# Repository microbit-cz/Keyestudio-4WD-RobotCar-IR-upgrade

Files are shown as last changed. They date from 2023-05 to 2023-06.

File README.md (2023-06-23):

[IR_MD]: /assets/languages/master/ir_setup.md
[models_MD]: /assets/languages/master/models_download.md
[crimping_MD]: /assets/languages/master/crimping_cables.md
[nuts_MD]: /assets/languages/master/nut_insertion.md
[charge_MD]: /assets/languages/master/charging_setup.md
[czechLanguage_MD]: /assets/languages/czech/README.cs.md
[englishLanguage_MD]: /README.md
[productFoto]: /assets/img/welcome.jpg

# Wall Detection and Integrated Charging addition for KS4031 Keyestudio 4WD Mecanum Robot Car

<kbd>[Czech][czechLanguage_MD]</kbd> <kbd>[English][englishLanguage_MD]</kbd>

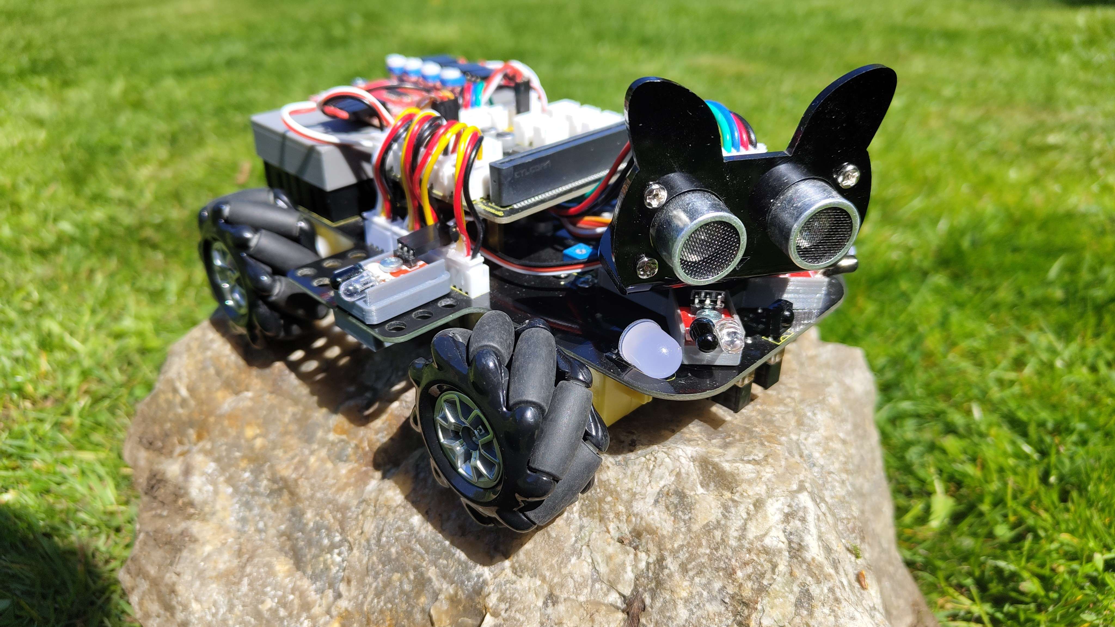
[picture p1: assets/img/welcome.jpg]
Welcome!


The **[wall detection][IR_MD]** feature uses sensors to detect the presence of obstacles in 180° radius such as walls and other objects in the car's path, allowing the car to automatically stop or change its direction to avoid collisions. This feature can be particularly useful in situations where the car is operating in a confined space or navigating through a complex environment such as Maze.

The **[integrated charging][charge_MD]** through USB-C can save time and improve convenience by allowing users to quickly and easily recharge the car without the need for additional equipment or cables.

## Documentation

- **[Download Models][models_MD]**
- [How to set-up wall detection][IR_MD]
- [How to set-up integrated charging][charge_MD]
- [Nut insertion][nuts_MD]
- [Cable crimping][crimping_MD]

---

## Functionality test

```js
pins.setPull(DigitalPin.P0, PinPullMode.PullNone);
pins.setPull(DigitalPin.P7, PinPullMode.PullNone);
pins.setPull(DigitalPin.P12, PinPullMode.PullNone);
pins.setPull(DigitalPin.P13, PinPullMode.PullNone);

while (true) {
  let front_P = pins.digitalReadPin(DigitalPin.P12);
  let front_L = pins.digitalReadPin(DigitalPin.P7);
  let left = pins.digitalReadPin(DigitalPin.P0);
  let right = pins.digitalReadPin(DigitalPin.P13);

  console.log("front_P: " + front_P);
  console.log("front_L: " + front_L);
  console.log("left: " + left);
  console.log("right: " + right);
  pause(100);
}
```

The given code snippet assigns the digital readings from the IR sensors to respective variables: front_P, front_L, left, and right. The console.log statements display the values of each sensor to the Console.

---

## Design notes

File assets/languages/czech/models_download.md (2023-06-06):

# Modely ke stažení

Zde jsou odkazy ke stažení modelů ve dvou různých formátech.

---

## Přidání IR senzoru

| Model | .SLDPRT | .STL | reference photo |
| --- | --- | --- | --- |
| **Balíček**  | [Stáhnout](/assets/models/IR_bundle_SLDPRT.zip) | [Stáhnout](/assets/models/stl/IR_bundle_STL.zip) | --------------------------- |
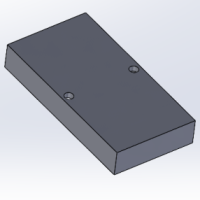
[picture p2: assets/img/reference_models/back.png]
back lid
| Zadní Víko | [Stáhnout](/assets/models/back.SLDPRT) | [Stáhnout](/assets/models/stl/back.STL) |  |
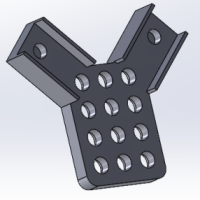
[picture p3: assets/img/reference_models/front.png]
front piece
| Přední díl  | [Stáhnout](/assets/models/front.SLDPRT) | [Stáhnout](/assets/models/stl/front.STL) |  |
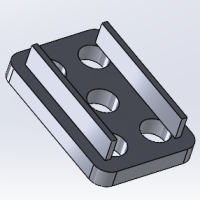
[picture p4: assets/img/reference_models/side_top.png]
side top piece
| Boční vrchní | [Stáhnout](/assets/models/side_top.SLDPRT) | [Stáhnout](/assets/models/stl/side_top.STL) |  |
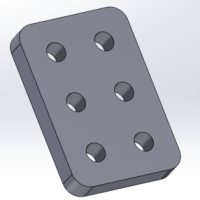
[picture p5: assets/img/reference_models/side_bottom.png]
side bottom piece
| Boční Spodní | [Stáhnout](/assets/models/side_bottom.SLDPRT) | [Stáhnout](/assets/models/stl/side_bottom.STL) |  |

## Integrované nabíjení

| Model | .SLDPRT | .STL | reference photo |
| --- | --- | --- | --- |
| **Balíček**  | [Stáhnout](/assets/models/Charger_bundle_SLDPRT.zip) | [Stáhnout](/assets/models/stl/Charger_bundle_STL.zip) | --------------------------- |
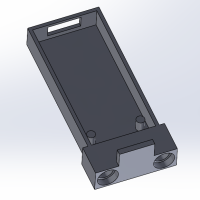
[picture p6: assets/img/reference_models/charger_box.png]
Box nabíječe
| Charger Box | [Stáhnout](/assets/models/charger_box.SLDPRT) | [Stáhnout](/assets/models/stl/charger_box.STL) |  |
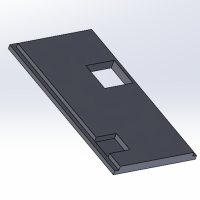
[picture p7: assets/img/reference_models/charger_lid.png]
Charger Lid
| Víko nabíječe | [Stáhnout](/assets/models/charger_lid.SLDPRT) | [Stáhnout](/assets/models/stl/charger_lid.STL) |  |

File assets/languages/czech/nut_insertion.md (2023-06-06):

# Jak vložit zasouvací matici

## Krok 1:

Ujistěte se, že je 3D vytištěný díl čistý a bez jakýchkoli nečistot nebo hrubých hran. V případě potřeby použijte smirkový papír k vyhlazení případných nerovností.

## Krok 2: Příprava zasouvací matice

Pomocí kleští přidržte matici na místě a vložte šroub do otvoru se závitem, abyste se ujistili, že jsou závity čisté a vyrovnané.

## Krok 3: Nasaďte zasouvací matici

Opatrně nasaďte nasazovací matici (závitem dolů) na otvor 3D tištěného dílu. Přidržte matici na místě pomocí kleští a ujistěte se, že je v otvoru vyrovnaná a vycentrovaná.

## Krok 4: Pájecí pistolí zahřejte matici 

S nasazenou maticí se dotkněte hrotem pájecí pistole matice. Na několik sekund přiložte teplo, dokud se matice nezačne tavit do 3D tištěného dílu, a ujistěte se, že na horní straně zůstává ~1 mm.

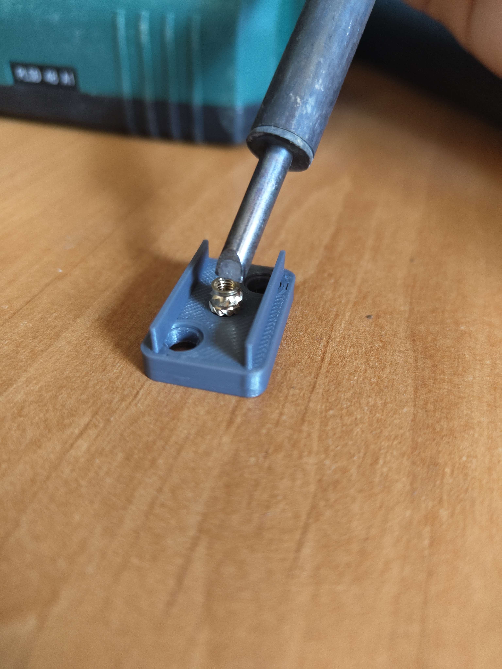
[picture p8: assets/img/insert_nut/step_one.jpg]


## Krok 5: Nechte vychladnout

Jakmile se matice roztaví v 3D tištěném dílu, vyjměte pájecí pistoli a nechte díl vychladnout. To by mělo trvat jen několik sekund.

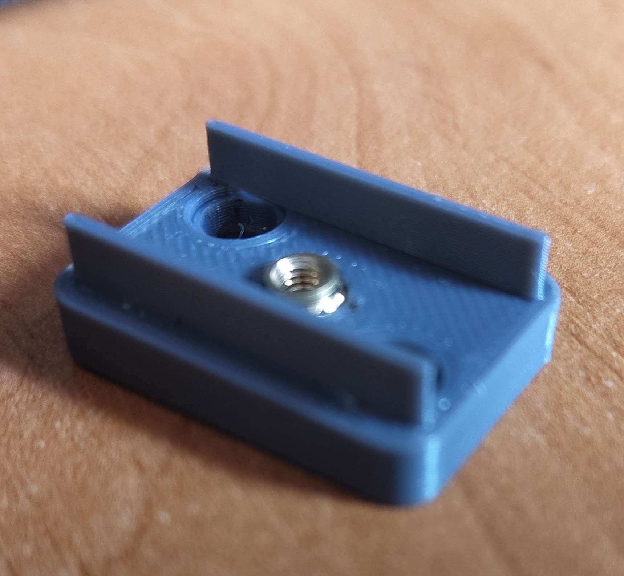
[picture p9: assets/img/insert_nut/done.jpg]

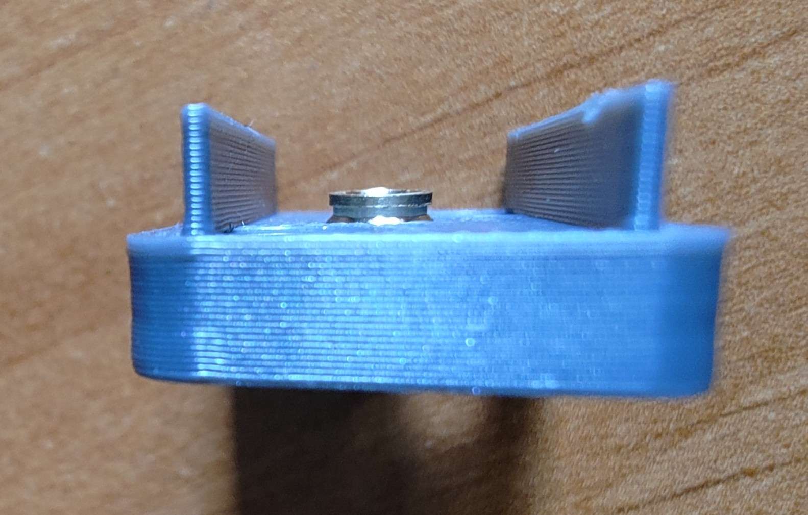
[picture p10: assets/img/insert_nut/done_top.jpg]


---

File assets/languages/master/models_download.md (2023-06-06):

# Model Downloads

Here are the downloadable links for the models in two different formats.

---

## IR sensor addition

| Model | .SLDPRT | .STL | reference photo |
| --- | --- | --- | --- |
| **BUNDLE**  | [Download](/assets/models/IR_bundle_SLDPRT.zip) | [Download](/assets/models/stl/IR_bundle_STL.zip) | --------------------------- |
| Back Lid | [Download](/assets/models/back.SLDPRT) | [Download](/assets/models/stl/back.STL) | back lid |
| Front Part  | [Download](/assets/models/front.SLDPRT) | [Download](/assets/models/stl/front.STL) | front piece |
| Side Top | [Download](/assets/models/side_top.SLDPRT) | [Download](/assets/models/stl/side_top.STL) | side top piece |
| Side Bottom | [Download](/assets/models/side_bottom.SLDPRT) | [Download](/assets/models/stl/side_bottom.STL) | side bottom piece |

## Integrated charging addition

| Model | .SLDPRT | .STL | reference photo |
| --- | --- | --- | --- |
| **BUNDLE**  | [Download](/assets/models/Charger_bundle_SLDPRT.zip) | [Download](/assets/models/stl/Charger_bundle_STL.zip) | --------------------------- |
| Charger Box | [Download](/assets/models/charger_box.SLDPRT) | [Download](/assets/models/stl/charger_box.STL) | Charger Box |
| Charger Lid | [Download](/assets/models/charger_lid.SLDPRT) | [Download](/assets/models/stl/charger_lid.STL) | Charger Lid |

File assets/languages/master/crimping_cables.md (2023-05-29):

# How to Crimp Dupont Cables

Materials you will need:

- Dupont connector pins
- Dupont connector housing
- Crimping tool
- Wire cutter (knife or pliers)
- Stranded wire

## Step 1: Cut the wire to the desired length

Using the wire cutter, cut the stranded wire to the desired length. Make sure to leave a little extra length for crimping.

## Step 2: Insert the wire into the connector pin

Insert the stripped end of the wire into the connector pin. Make sure the wire goes all the way into the pin and that the strands are lined up evenly with the end of the pin.

## Step 3: Crimp the connector pin

Using the crimping tool, crimp the pin onto the wire. Be sure to position the crimping tool so that it is centered on the pin and that the jaws of the tool are fully engaged before squeezing.

## Step 4: Insert the pin into the connector housing

Insert the pin into the appropriate slot in the connector housing. Make sure the pin clicks into place and that the wire is held firmly in the housing.

## Step 5: Repeat for other wires

Repeat steps 2-4 for each wire that needs to be crimped onto a connector pin.

## Step 6: Connect the connectors

Once all the wires are crimped and inserted into the connector housing, you can connect the connectors to each other. Be sure to match the pins and sockets properly so that they click into place and the connection is secure.

---

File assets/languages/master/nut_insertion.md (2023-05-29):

# How to insert a Insertion Nut

## Step 1:

Make sure the 3D printed part is clean and free of any debris or rough edges. If necessary, use sandpaper to smooth out any rough spots.

## Step 2: Prepare the insertion nut

Using pliers, hold the nut in place and insert a screw into the threaded hole to make sure the threads are clean and aligned.

## Step 3: Insert the insertion nut

Carefully place the insertion nut (thread down) on the hole of the 3D printed part. Hold the nut in place with pliers, ensuring that it is level and centered in the hole.

## Step 4: Apply heat with the soldering gun

With the insertion nut held in place, touch the tip of the soldering gun to the nut. Apply heat for a few seconds, until the nut begins to melt into the 3D printed part, make sure you leave ~1mm on the top.

Reference Photo

## Step 5: Allow to cool

Once the nut has melted into the 3D printed part, remove the soldering gun and allow the part to cool. This should only take a few seconds.

Reference Photo
Reference Photo

---

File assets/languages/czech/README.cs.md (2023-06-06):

[IR_MD]: /assets/languages/czech/ir_setup.md
[models_MD]: /assets/languages/czech/models_download.md
[crimping_MD]: /assets/languages/czech/crimping_cables.md
[nuts_MD]: /assets/languages/czech/nut_insertion.md
[charge_MD]: /assets/languages/czech/charging_setup.md
[czechLanguage_MD]: README.cs.md
[englishLanguage_MD]: /README.md
[productFoto]: /assets/img/welcome.jpg

# Detekce na zdi a integrované nabíjení pro robotické auto KS4031 Keyestudio 4WD Mecanum

<kbd>[Czech][czechLanguage_MD]</kbd> <kbd>[English][englishLanguage_MD]</kbd>

Welcome!

Funkce **[detekce stěn][IR_MD]** využívá senzory k detekci přítomnosti překážek v okruhu 180°, jako jsou stěny a další objekty v dráze vozu, a umožňuje vozu automaticky zastavit nebo změnit směr jízdy, aby se vyhnul kolizi. Tato funkce může být užitečná zejména v situacích, kdy se vůz pohybuje v omezeném prostoru nebo projíždí složitým prostředím, jako je například Bludiště.

**[Integrované nabíjení][charge_MD]** přes USB-C může ušetřit čas a zvýšit pohodlí, protože umožňuje uživatelům rychle a snadno dobíjet auto bez potřeby dalšího vybavení nebo kabelů.

## Dokumentace

- **[Modely ke stažení][models_MD]**
- [Jak nastavit detekci stěn][IR_MD]
- [Jak nastavit integrované nabíjení][charge_MD]
- [Vsázení matic][nuts_MD]
- [Krimpování kabelů][crimping_MD]

---

## Test funkčnosti

```js
pins.setPull(DigitalPin.P0, PinPullMode.PullNone);
pins.setPull(DigitalPin.P7, PinPullMode.PullNone);
pins.setPull(DigitalPin.P12, PinPullMode.PullNone);
pins.setPull(DigitalPin.P13, PinPullMode.PullNone);

while (true) {
  let front_P = pins.digitalReadPin(DigitalPin.P12);
  let front_L = pins.digitalReadPin(DigitalPin.P7);
  let left = pins.digitalReadPin(DigitalPin.P0);
  let right = pins.digitalReadPin(DigitalPin.P13);

  console.log("front_P: " + front_P);
  console.log("front_L: " + front_L);
  console.log("left: " + left);
  console.log("right: " + right);
  pause(100);
}
```

Uvedený úryvek kódu přiřadí digitální údaje z infračervených senzorů příslušným proměnným: front_P, front_L, left a right. Příkazy console.log zobrazí hodnoty jednotlivých senzorů do konzoly

---

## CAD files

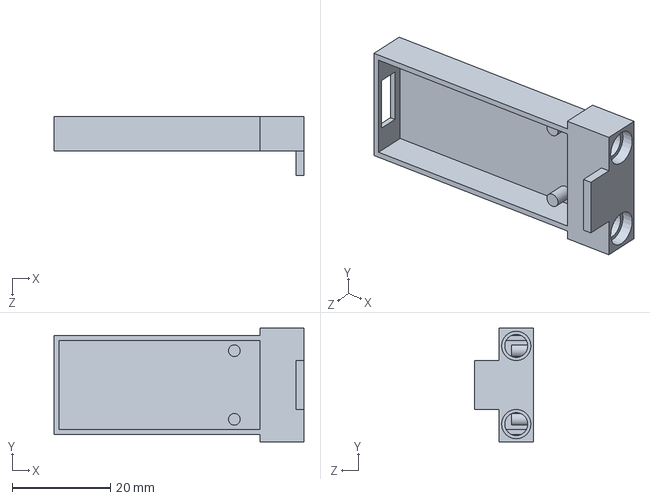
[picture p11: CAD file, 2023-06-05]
assets/models/charger_box.SLDPRT
51.0 x 23.2 x 12.0 mm

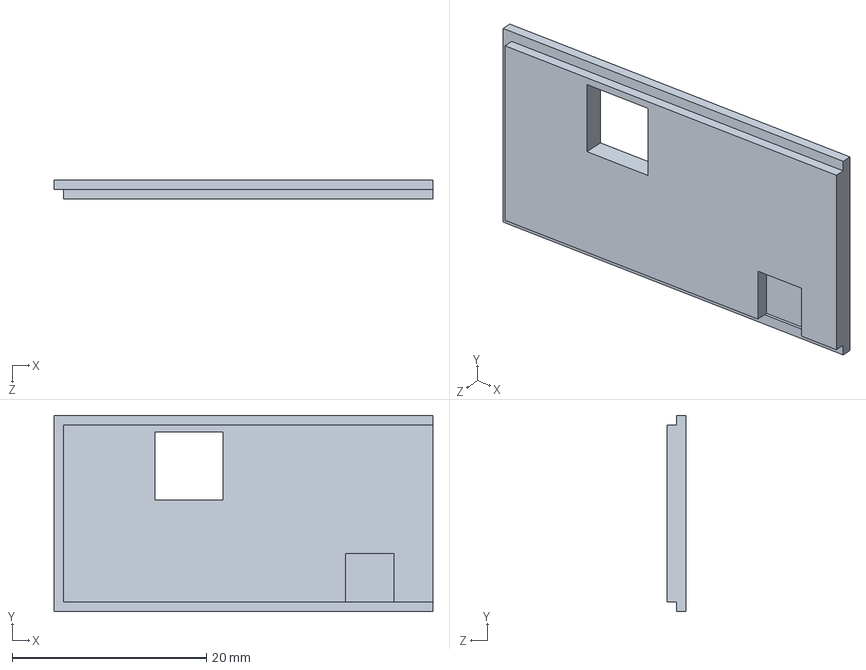
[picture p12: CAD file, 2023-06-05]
assets/models/charger_lid.SLDPRT
39.0 x 20.2 x 2.00 mm

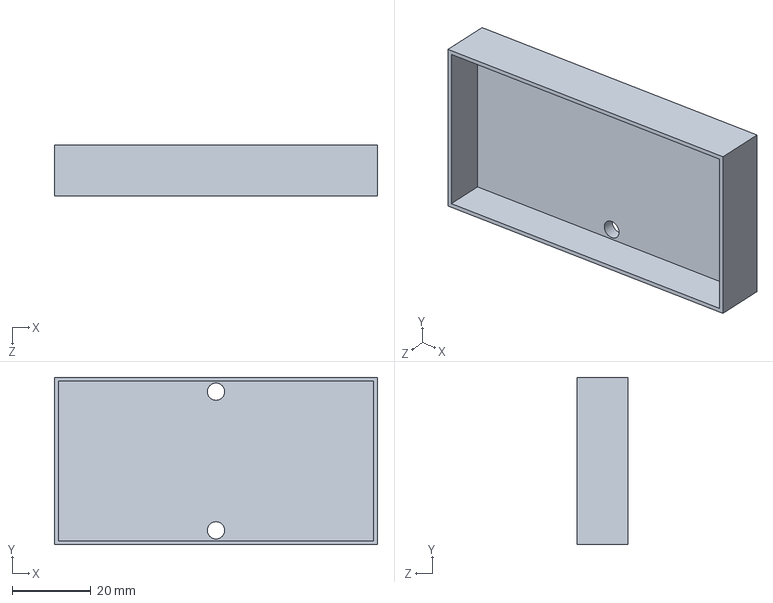
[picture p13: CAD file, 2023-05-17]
assets/models/back.SLDPRT
82.0 x 42.5 x 13.0 mm

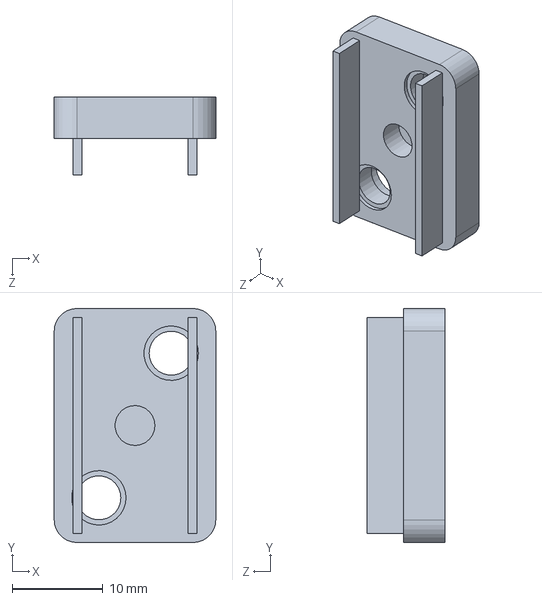
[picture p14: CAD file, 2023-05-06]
assets/models/side_top.SLDPRT
17.8 x 25.8 x 8.60 mm

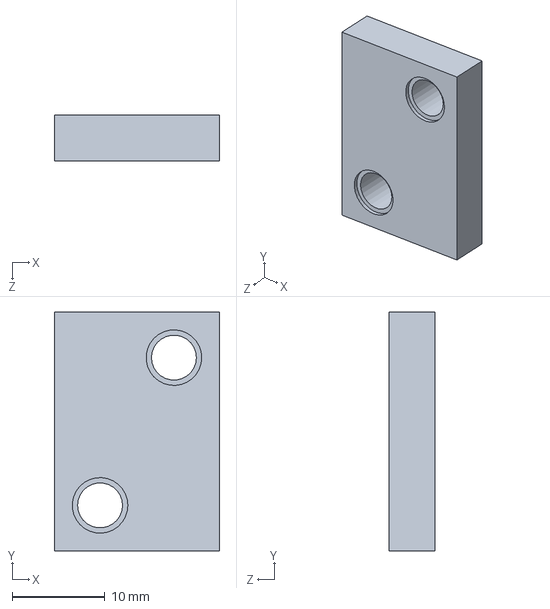
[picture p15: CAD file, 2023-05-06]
assets/models/side_bottom.SLDPRT
17.8 x 25.8 x 5.00 mm

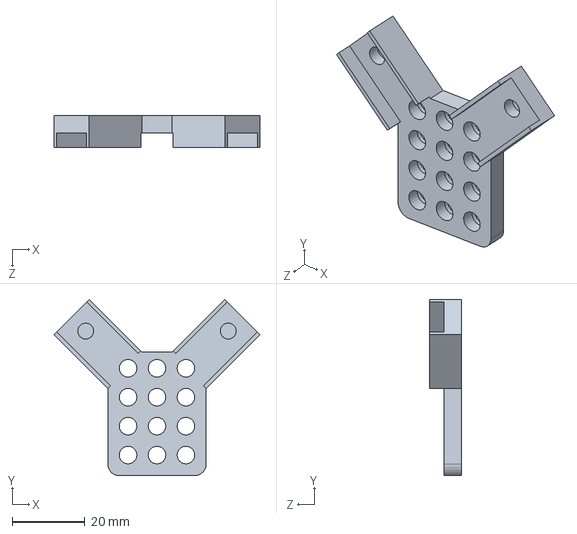
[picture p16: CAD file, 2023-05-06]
assets/models/front.SLDPRT
56.7 x 48.6 x 8.70 mm

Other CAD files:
assets/models/stl/back.STL
assets/models/stl/charger_box.STL
assets/models/stl/charger_lid.STL
assets/models/stl/front.STL
assets/models/stl/side_bottom.STL
assets/models/stl/side_top.STL

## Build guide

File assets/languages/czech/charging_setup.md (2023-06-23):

[charger]: https://www.aliexpress.com/item/1005004872791816.html "Multi-Cell 2S 3S 4S Type-C To 8.4V 12.6V 16.8V Step-Up Boost LiPo Polymer Li-Ion Charger 7.4V 11.1V 14.8V 18650 Lithium Battery"
[wire]: https://www.aliexpress.com/item/1005003250004004.html "10PCS JST XH 2.54-2 Pin Battery Connector Plug Male with 100MM 200MM Wire"
[lego_pieces]: https://www.aliexpress.com/item/1005004975645306.html "Bolt Pin with Friction Peg Cross Axle Building Block Bricks Connector Technical 32002 MOC Parts Assemble Particles Toy"
[cables]: crimping_cables.md
[models]: models_download.md

# Návod - Nabíječ

<table>
  <thead>
    <tr>
      <th>list dílů</th>
      <th>referenční foto</th>
    </tr>
  </thead>
  <tbody>
    <tr>
      <td>
        <ul>
         <li>1x <strong><a href="https://www.aliexpress.com/item/32910726663.html">Nabíječ</a></strong></li>
         <li>2x <strong>Lego Kolíček</strong> typu <a href="https://www.aliexpress.com/item/1005004975645306.html">32002</a></li><br>
         <li><strong><a href="models_download.md">modely</a></strong>
            <ul>
                <li>1x box nabíječe</li>
                <li>1x víko nabíječe</li>
            </ul>
         </li>
         <li><strong><a href="crimping_cables.md">kabely</a></strong>
            <ul>
                <li>1x 2pin JST XH 5cm</li>
            </ul>
         </li>
        </ul>
      </td>
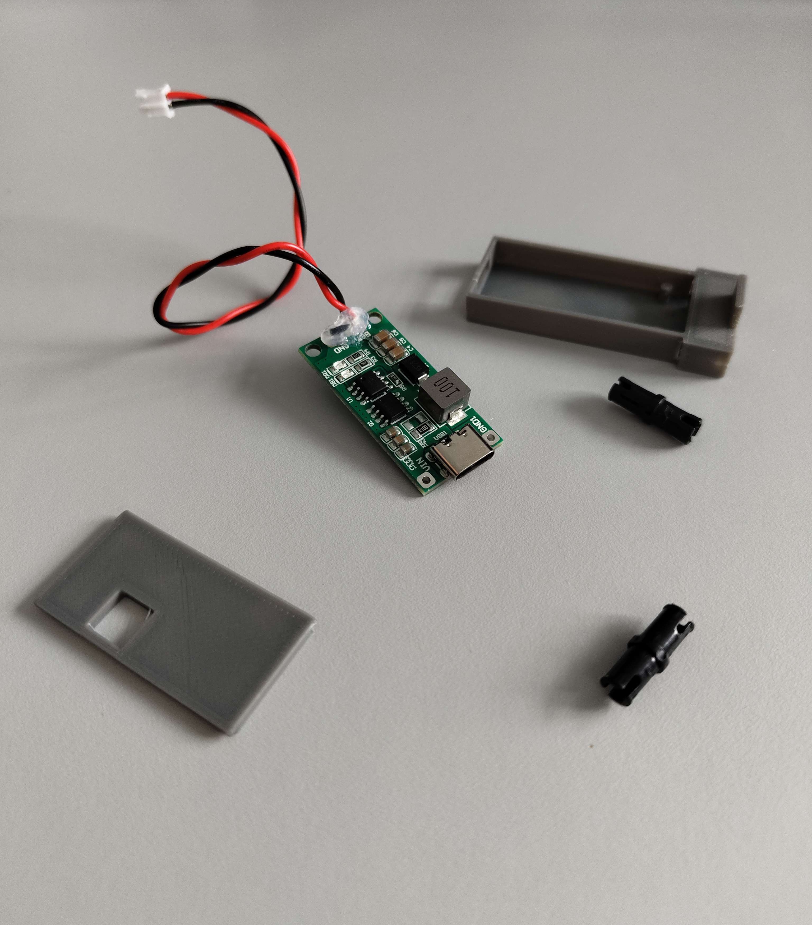
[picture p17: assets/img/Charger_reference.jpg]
Reference Photo
      <td></td>
    </tr>
  </tbody>
</table>

All parts were bought on Aliexpress and on 2.6.2023 it cost **84,33Kč** without shipping:

| Díl | Cena | DPH za dopravu | Požadované množství | Cena za požadované množství |
| --- | :---: | :---: | :---: | :---: |
| [2S Type-C To 8.4V Step-Up LiPo Charger][charger] - výběr: _2S 2A_ | 22,45Kč | 8,59Kč | 1x | 22,45Kč |
| [JST XH 2.54-2 Pin Plug Male][wire] - výběr: _length 100MM 10pcs_  | 6,61Kč | 28,85Kč | 1x | 0,66Kč |
| [LEGO Technic Pin 32002][lego_pieces] - výběr: _50pcs_ | 55,27Kč | ZDARMA | 2x | 2,20Kč |
| **Součet:** | **84,33Kč** |  **37,43Kč** | -- | **25,32Kč** |

Za všechny produkty s dopravou do České republiky jsem zaplatil **121,74Kč**.

---

# Vkládání modelů

Před vložením [modelů][modelů] do vozu vytvořte potřebné [kabely][kabelů].

Při osazování modelů na auto je důležité se ujistit, že je vše řádně zajištěno a všechny kabely jsou správně zapojeny. Začněte zadním víkem. Připojte kabely k příslušným pinům na modulu.

Ujistěte se, že jsou všechny kabely uklizené a nepřekážejí pohyblivým částem. Po usazení všech modelů do vozu vyzkoušejte IR senzory, abyste se ujistili, že správně fungují. Po nasazení všech čtyř snímačů by mělo být auto schopno detekovat překážky ve všech směrech.

---

## Nabíječ

**Díly:**

- 1x víko nabíječky
- 2x Box na nabíječku
- 2x Kolíček LEGO typu 32002
- 1x 2pin dupont 5cm
- 1x [nabíjecí modul][nabíječka]
<table>
   <tr>
    <td valign="top">Krok 1: Připájení kabelu k modulu <br><b>
    &emsp; black - GND <br> &emsp; Red - BAT</b></td>
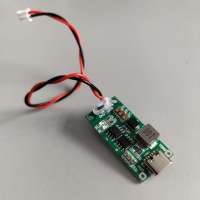
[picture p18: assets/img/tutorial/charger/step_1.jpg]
step1
    <td valign="top"></td>
  </tr>
  <tr>
    <td valign="top">Krok 2: Vložte nabíječ do modelu</td>
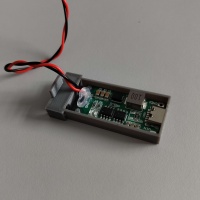
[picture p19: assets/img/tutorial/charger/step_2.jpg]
step2
    <td valign="top"></td>
  </tr>
    <tr>
    <td valign="top">Krok 3: nasaďte víko na místo</td>
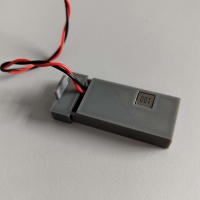
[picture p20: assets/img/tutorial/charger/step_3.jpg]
step3
    <td valign="top"></td>
  </tr>
  <tr>
    <td valign="top">Krok 4: Vložte dílky lega do modelu</td>
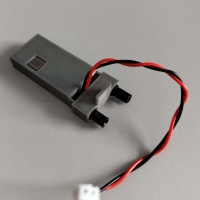
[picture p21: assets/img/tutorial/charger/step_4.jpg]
step4
    <td valign="top"></td>
  </tr>
  <tr>
    <td valign="top">Krok 5: vložte modul na auto</td>
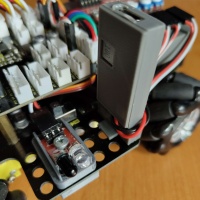
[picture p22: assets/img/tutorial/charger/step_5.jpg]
step5
    <td valign="top"></td>
  </tr>
    <tr>
    <td valign="top">Krok 6: připojte kabel</td>
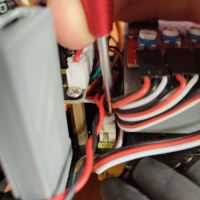
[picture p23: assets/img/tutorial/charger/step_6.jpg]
step6
    <td valign="top"></td>
  </tr>
</table>

---

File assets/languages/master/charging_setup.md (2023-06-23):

[charger]: https://www.aliexpress.com/item/1005004872791816.html "Multi-Cell 2S 3S 4S Type-C To 8.4V 12.6V 16.8V Step-Up Boost LiPo Polymer Li-Ion Charger 7.4V 11.1V 14.8V 18650 Lithium Battery"
[wire]: https://www.aliexpress.com/item/1005003250004004.html "10PCS JST XH 2.54-2 Pin Battery Connector Plug Male with 100MM 200MM Wire"
[lego_pieces]: https://www.aliexpress.com/item/1005004975645306.html "Bolt Pin with Friction Peg Cross Axle Building Block Bricks Connector Technical 32002 MOC Parts Assemble Particles Toy"
[cables]: crimping_cables.md
[models]: models_download.md

# Tutorial - Charger addition

<table>
  <thead>
    <tr>
      <th>Parts List</th>
      <th>Reference Photo</th>
    </tr>
  </thead>
  <tbody>
    <tr>
      <td>
        <ul>
         <li>1x <strong><a href="https://www.aliexpress.com/item/32910726663.html">Charger Module</a></strong></li>
         <li>2x <strong>Lego Pin</strong> type <a href="https://www.aliexpress.com/item/1005004975645306.html">32002</a></li><br>
         <li><strong><a href="models_download.md">Models</a></strong>
            <ul>
                <li>1x Charger Box</li>
                <li>1x Charger Lid</li>
            </ul>
         </li>
         <li><strong><a href="crimping_cables.md">Cables</a></strong>
            <ul>
                <li>1x 2pin JST XH 5cm</li>
            </ul>
         </li>
        </ul>
      </td>
      <td>Reference Photo</td>
    </tr>
  </tbody>
</table>

All parts were bought on Aliexpress and on 2.6.2023 it cost **3.83$** without shipping:

| Part | Price | shipping VAT | Quantity required | Price for required Quantity |
| --- | :---: | :---: | :---: | :---: |
| [2S Type-C To 8.4V Step-Up LiPo Charger][charger] - choice: _2S 2A_ | 1.02$ | 0.39$ | 1x | 1.02$ |
| [JST XH 2.54-2 Pin Plug Male][wire] - choice: _length 100MM 10pcs_  | 0.30$ | 1.31$ | 1x | 0.03$ |
| [LEGO Technic Pin 32002][lego_pieces] - choice: _50pcs_ | 2.51$ | FREE | 2x | 0.1$ |
| **Sum:** | **3.83$** | **1.7$** | -- | **1.15$** |

For all the products with shipping to Czech Republic i paid **5.53$**.

---

# Embedding Models

Before Embeding [models][models] onto the car create the needed [cables][cables].

When embedding the models onto the car, it is important to make sure that everything is secured properly and all cables are connected correctly. Start with the back lid. Connect the cables to the appropriate pins on the module.

Make sure all cables are tidy and out of the way of any moving parts. Once all models are embedded onto the car, test the IR sensors to ensure they are working properly. With all four sensors in place, the car should be able to detect obstacles in all directions.

---

## Charger

**Parts:**

- 1x Charger Lid
- 2x Charger Box
- 2x LEGO Pin type 32002
- 1x 2pin dupont 5cm
- 1x [Charger module][charger]

<table>
   <tr>
    <td valign="top">Step 1: Solder the cable onto the module <br><b>
    &emsp; black - GND <br> &emsp; Red - BAT</b></td>
    <td valign="top">step1</td>
  </tr>
  <tr>
    <td valign="top">Step 2: Insert the charger into the  model</td>
    <td valign="top">step2</td>
  </tr>
    <tr>
    <td valign="top">Step 3: place the Lid in place</td>
    <td valign="top">step3</td>
  </tr>
  <tr>
    <td valign="top">Step 4: Insert the lego pieces into the model</td>
    <td valign="top">step4</td>
  </tr>
  <tr>
    <td valign="top">Step 5: Place the model on the car</td>
    <td valign="top">step5</td>
  </tr>
    <tr>
    <td valign="top">Step 6: Connect the cable</td>
    <td valign="top">step6</td>
  </tr>
</table>

---

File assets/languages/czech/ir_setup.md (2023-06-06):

[4_channel_IR]: https://www.aliexpress.com/item/1638741453.html "Four Way 4 Channel Infrared Detector Tracing Transmission Line Obstacle Avoidance Sensor Module Diy Car Robot"
[insert]: https://www.aliexpress.com/item/1005003582355741.html "M2 M2.5 M3 M4 M5 M6 Brass Hot Melt Insert Knurled Nut Thread Heat Molding Double Twill Injection Embedment Nut For 3D Printer"
[screws]: https://www.aliexpress.com/item/4000025462486.html "25pcs Computer PC Case 2.5 3.5 inch Hard Drive Disk HDD Caddy Hot Swap Server Tray Mount Screw Phillips Countersunk Head Bolt"
[lego_pieces]: https://www.aliexpress.com/item/1005004975645306.html "Bolt Pin with Friction Peg Cross Axle Building Block Bricks Connector Technical 32002 MOC Parts Assemble Particles Toy"
[housing]: https://www.aliexpress.com/item/32816638128.html "100PCS Dupont Head 2.54mm 1X 1P 2P 3P 4P 1X1P 1X2P Dupont Plastic Shell Pin Head Connector Jumper Wire Cable Housing Plug Female"
[female]: https://www.aliexpress.com/item/32816638128.html "100PCS Dupont Head 2.54mm 1X 1P 2P 3P 4P 1X1P 1X2P Dupont Plastic Shell Pin Head Connector Jumper Wire Cable Housing Plug Female"
[wire]: https://www.aliexpress.com/item/4000615921627.html "100PCS Dupont Head 2.54mm 1X 1P 2P 3P 4P 1X1P 1X2P Dupont Plastic Shell Pin Head Connector Jumper Wire Cable Housing Plug Female"
[insert_nut]: nut_insertion.md
[cables]: crimping_cables.md
[models]: models_download.md

# Návod - 4kanálový infračervený senzorový modul

<table>
  <thead>
    <tr>
      <th>list dílů</th>
      <th>referenční foto</th>
    </tr>
  </thead>
  <tbody>
    <tr>
      <td>
        <ul>
         <li>1x <strong><a href="https://www.aliexpress.com/item/32910726663.html">4kanálový infračervený senzorový modul</a></strong></li>
         <li>8x <strong>Lego kolíček</strong> typu <a href="https://www.aliexpress.com/item/1005004975645306.html">32002</a></li>
         <li>6x <strong>vsuvné matice</strong> typu <a href="https://www.aliexpress.com/item/1005004629314742.html">M3x4x4.2</a></li>
         <li>6x <strong>šroub</strong> typu <a href="https://www.aliexpress.com/item/1005005098799689.html">M3x4mm</a></li>
         <li><strong><a href="models_download.md">modely</a></strong>
            <ul>
                <li>1x Přední držák</li>
                <li>2x boční držák - horní díl</li>
                <li>2x boční držák - spodní díl</li>
                <li>1x zadní víko</li>
            </ul>
         </li>
         <li><strong><a href="crimping_cables.md">kabely</a></strong>
            <ul>
                <li>2x 3pin dupont 20cm</li>
                <li>2x 3pin dupont 15cm</li>
                <li>1x 1pin dupont 8cm</li>
                <li>1x 2pin dupont 8cm</li>
                <li>1x 3pin dupont 5cm</li>
            </ul>
         </li>
        </ul>
      </td>
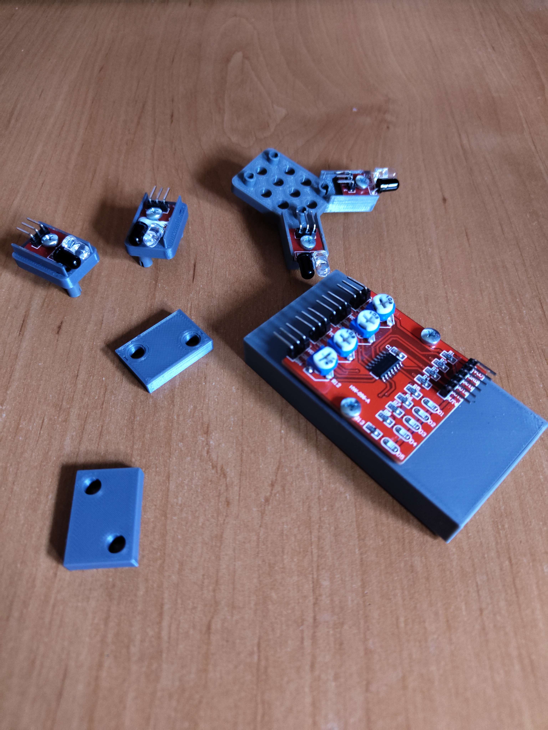
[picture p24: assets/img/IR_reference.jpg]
Reference Photo
      <td></td>
    </tr>
  </tbody>
</table>

Všechny díly byly zakoupeny na Aliexpressu a 2.6.2023 stály **215,13Kč** bez poštovného:

| Díl | Cena | DPH za dopravu | Požadované množství | Cena za požadované množství |
| --- | :---: | :---: | :---: | :---: |
| [4-way F233-01][4_channel_IR] | 27,28Kč | 10,78Kč | 1x | 27,28Kč |
| [2,5 šrouby s plochou hlavou ][screws] - výběr: _M3x4mm_ | 44,21Kč | ZDARMA | 6x | 10,60Kč |
| [LEGO Technic Pin 32002][lego_pieces] - výběr: _50pcs_ | 55,21Kč | ZDARMA | 8x | 8,84Kč |
| [Mosazná tavná vložka M3 s vroubkovanou maticí][insert] - výběr: _M3(OD4,2mm)_ , _Length 3mm 50pcs_ | 11,00Kč | 45,10Kč | 6x | 1,32Kč |
| [3pin drát 26AWG][wire] - výběr: _30 core 5 meters_ | 32,77 | 45,10Kč | ~ 90cm | 5,90Kč |
| [Pouzdro Dupont][housing] - výběr: _1X3P_ | 23,76Kč | 5,94Kč | 10x | 2,38Kč |
| [Dupont Terminal][female] - výběr: _Dupont Terminal_ | 20,90Kč | 5,94Kč | 36x | 7,52Kč |
| **Součet:** | **215,13Kč** | **112,84** | -- | **63,84Kč** |

Za všechny produkty s dopravou do České republiky jsem zaplatil **327,98Kč**.

---

# Vkládání modelů

Před vložením [modelů][models] do vozu vytvořte potřebné [kabely][cables] a vložte všechny potřebné [vložné matice][insert_nut].

Při osazování modelů na vůz je důležité se ujistit, že je vše řádně zajištěno a všechny kabely jsou správně připojeny. Začněte zadním víkem. Připojte kabely k příslušným pinům na modulu.

Ujistěte se, že jsou všechny kabely uklizené a nepřekážejí žádným pohyblivým částem. Po usazení všech modelů do vozu vyzkoušejte IR senzory, abyste se ujistili, že správně fungují. Po nasazení všech čtyř snímačů by mělo být auto schopno detekovat překážky ve všech směrech.

---

## Zadní víko

**Díly:**

- 1x zadní víko
- 2x nasazovací matice
- 2x šrouby
- 1x 3pin dupont 5cm
- 1x 2pin dupont 8cm
- 1x 1pin dupont 8cm
- 1x [4kanálový infračervený senzorový modul][4_channel_IR]

<table>
  <tr>
    <td valign="top">Krok 1: <a href="nut_insertion.md">vložte do modelu 2 nasazovací matice.</a></td>
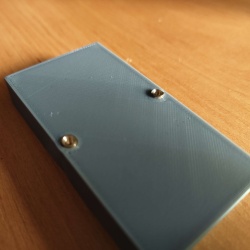
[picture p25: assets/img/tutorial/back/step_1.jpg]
step1
    <td valign="top"></td>
  </tr>
  <tr>
    <td valign="top">Krok 2: našroubujte IR modul</td>
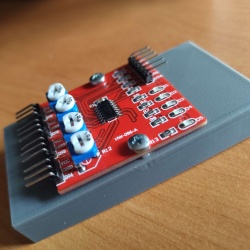
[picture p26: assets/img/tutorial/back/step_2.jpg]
step2
    <td valign="top"></td>
  </tr>
  <tr>
    <td valign="top">Krok 3: připojte <a href="crimping_cables.md">kabely</a> 
    <ul>
        <li>Připojte napájecí a zemnicí kabely:
            <ul>
              <li>5V - VCC</li>
              <li>G - GND</li>
            </ul>
        </li>
        <li>Připojte senzory
          <ul>
            <li>Levý sensor: P0 - OUT1</li>    
            <li>Levý přední sensor: P7 - OUT2</li>
            <li>Pravý přední sensor: P12 - OUT3</li>
            <li>Pravý sensor: P13 - OUT4</li>
          <ul>
        </li>
    </ul>
    </td>
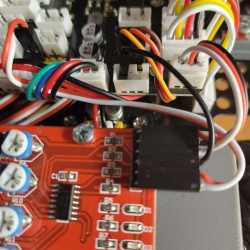
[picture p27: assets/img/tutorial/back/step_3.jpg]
step3
    <td valign="top"></td>
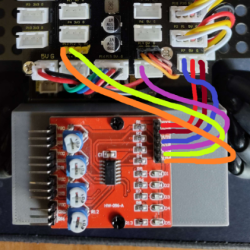
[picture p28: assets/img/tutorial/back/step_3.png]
step3
    <td valign="top"></td>
  </tr>
</table>

---

## Přední díl

**Díly:**

- 1x přední držák
- 4x Kolíček LEGO typu 32002
- 2x zasouvací matice
- 2x šrouby
- 2x 3pin dupont 20cm
- 2x infračervené senzory z [4kanálového infračerveného senzorového modulu][4_channel_IR]

<table>
  <tr>
    <td valign="top">Krok 1: <a href="nut_insertion.md">vložte do modelu 2 nasazovací matice.</a></td>
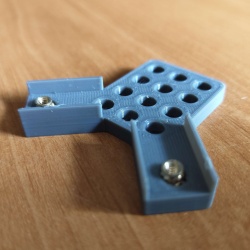
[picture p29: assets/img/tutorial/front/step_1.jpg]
step1
    <td valign="top"></td>
  </tr>
  <tr>
    <td valign="top">Krok 2: Vložte 1 kolík LEGO do každého rohu přední desky LEGO.</td>
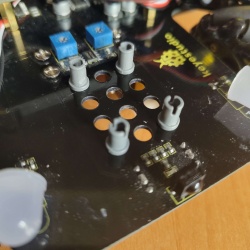
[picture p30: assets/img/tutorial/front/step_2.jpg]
step2
    <td valign="top"></td>
  </tr>
  <tr>
    <td valign="top">Krok 3: Umístěte model na kolíky lega</td>
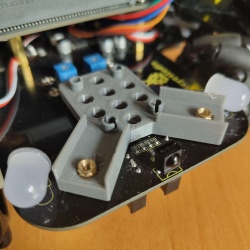
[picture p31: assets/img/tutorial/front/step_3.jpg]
step3
    <td valign="top"></td>
  </tr>
  <tr>
    <td valign="top">Krok 4: Našroubování IR senzorů do zasouvacích matic</td>
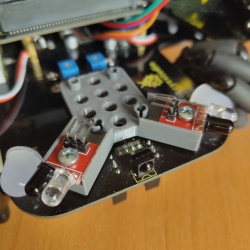
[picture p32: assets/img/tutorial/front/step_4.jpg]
step4
    <td valign="top"></td>
  </tr>
  <tr>
    <td valign="top">Krok 5: Připojte <a href="crimping_cables.md">kabely</a></td>
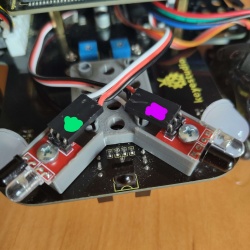
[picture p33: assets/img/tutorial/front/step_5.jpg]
step5
    <td valign="top"></td>
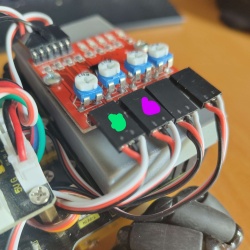
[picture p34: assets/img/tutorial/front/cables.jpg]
    <td valign="top"></td>
  </tr>
  <tr>
    <td valign="top">Krok 6: Umístěte ultrazvukový senzor na horní stranu</td>
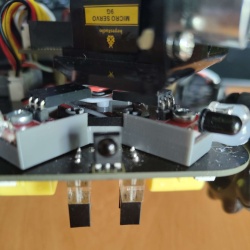
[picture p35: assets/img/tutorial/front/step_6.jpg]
step6
    <td valign="top"></td>
  </tr>
</table>

---

## Boční díl

**Díly:**

- 2x boční držák - horní díl
- 2x boční držák - spodní díl
- 4x kolík LEGO typ 32002
- 2x zasouvací matice
- 2x šrouby
- 2x 3pin dupont 15cm
- 2x infračervené senzory z [4kanálového infračerveného senzorového modulu][4_channel_IR]

<table>
  <tr>
    <td valign="top">Krok 1: <a href="nut_insertion.md">vložte do modelů 2 nasazovací matice.</a></td>
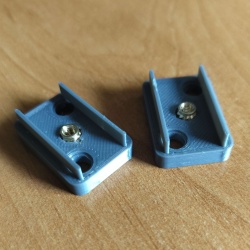
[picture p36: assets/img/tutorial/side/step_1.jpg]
step1
    <td valign="top"></td>
  </tr>
  <tr>
    <td valign="top">Krok 2: Vložte kolíky LEGO do horní části desky LEGO</td>
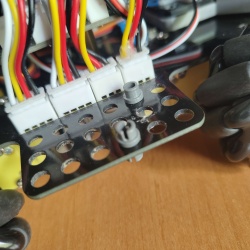
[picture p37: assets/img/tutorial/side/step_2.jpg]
step2
    <td valign="top"></td>
  </tr>
  <tr>
    <td valign="top">Krok 3: Umístěte spodní díl na dílky lega</td>
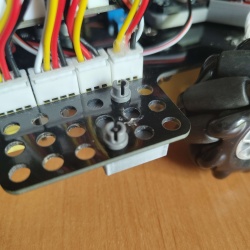
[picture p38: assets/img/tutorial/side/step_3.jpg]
step3
    <td valign="top"></td>
  </tr>
  <tr>
    <td valign="top">Krok 4: Umístěte horní díl na kolíky lega.</td>
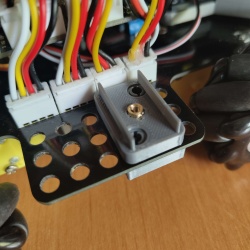
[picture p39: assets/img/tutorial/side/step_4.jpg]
step4
    <td valign="top"></td>
  </tr>
  <tr>
    <td valign="top">Krok 5: Připojte <a href="crimping_cables.md">kabely</a></td>
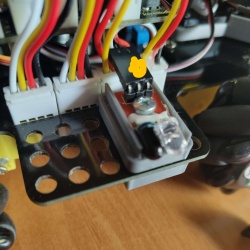
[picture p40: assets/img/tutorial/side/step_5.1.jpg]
step5
    <td valign="top"></td>
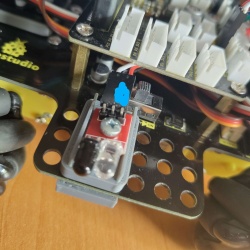
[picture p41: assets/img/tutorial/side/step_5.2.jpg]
step5
    <td valign="top"></td>
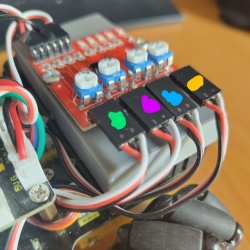
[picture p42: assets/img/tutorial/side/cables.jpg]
    <td valign="top"></td>
  </tr>
</table>

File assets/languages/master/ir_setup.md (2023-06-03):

[4_channel_IR]: https://www.aliexpress.com/item/1638741453.html "Four Way 4 Channel Infrared Detector Tracing Transmission Line Obstacle Avoidance Sensor Module Diy Car Robot"
[insert]: https://www.aliexpress.com/item/1005003582355741.html "M2 M2.5 M3 M4 M5 M6 Brass Hot Melt Insert Knurled Nut Thread Heat Molding Double Twill Injection Embedment Nut For 3D Printer"
[screws]: https://www.aliexpress.com/item/4000025462486.html "25pcs Computer PC Case 2.5 3.5 inch Hard Drive Disk HDD Caddy Hot Swap Server Tray Mount Screw Phillips Countersunk Head Bolt"
[lego_pieces]: https://www.aliexpress.com/item/1005004975645306.html "Bolt Pin with Friction Peg Cross Axle Building Block Bricks Connector Technical 32002 MOC Parts Assemble Particles Toy"
[housing]: https://www.aliexpress.com/item/32816638128.html "100PCS Dupont Head 2.54mm 1X 1P 2P 3P 4P 1X1P 1X2P Dupont Plastic Shell Pin Head Connector Jumper Wire Cable Housing Plug Female"
[female]: https://www.aliexpress.com/item/32816638128.html "100PCS Dupont Head 2.54mm 1X 1P 2P 3P 4P 1X1P 1X2P Dupont Plastic Shell Pin Head Connector Jumper Wire Cable Housing Plug Female"
[wire]: https://www.aliexpress.com/item/4000615921627.html "100PCS Dupont Head 2.54mm 1X 1P 2P 3P 4P 1X1P 1X2P Dupont Plastic Shell Pin Head Connector Jumper Wire Cable Housing Plug Female"
[insert_nut]: nut_insertion.md
[cables]: crimping_cables.md
[models]: models_download.md

# Tutorial - 4 way IR sensor addition

<table>
  <thead>
    <tr>
      <th>Parts List</th>
      <th>Reference Photo</th>
    </tr>
  </thead>
  <tbody>
    <tr>
      <td>
        <ul>
         <li>1x <strong><a href="https://www.aliexpress.com/item/32910726663.html">4 Channel Infrared Sensor Module</a></strong></li>
         <li>8x <strong>Lego Pin</strong> type <a href="https://www.aliexpress.com/item/1005004975645306.html">32002</a></li>
         <li>6x <strong>Insert nut</strong> type <a href="https://www.aliexpress.com/item/1005004629314742.html">M3x4x4.2</a></li>
         <li>6x <strong>Screw</strong> type <a href="https://www.aliexpress.com/item/1005005098799689.html">M3x4mm</a></li>
         <li><strong><a href="models_download.md">Models</a></strong>
            <ul>
                <li>1x Front holder</li>
                <li>2x side holder - top piece</li>
                <li>2x side holder - bottom piece</li>
                <li>1x back lid</li>
            </ul>
         </li>
         <li><strong><a href="crimping_cables.md">Cables</a></strong>
            <ul>
                <li>2x 3pin dupont 20cm</li>
                <li>2x 3pin dupont 15cm</li>
                <li>1x 1pin dupont 8cm</li>
                <li>1x 2pin dupont 8cm</li>
                <li>1x 3pin dupont 5cm</li>
            </ul>
         </li>
        </ul>
      </td>
      <td>Reference Photo</td>
    </tr>
  </tbody>
</table>

All parts were bought on Aliexpress and on 2.6.2023 it cost **9.78$** without shipping:

| Part | Price | shipping VAT | Quantity required | Price for required Quantity |
| --- | :---: | :---: | :---: | :---: |
| [4-way F233-01][4_channel_IR] | 1.24$ | 0.49$ | 1x | 1.24$ |
| [2.5 Screws Flat Head ][screws] - choice: _M3x4mm_ | 2.01$ | FREE | 6x | 0.482$ |
| [LEGO Technic Pin 32002][lego_pieces] - choice: _50pcs_ | 2.51$ | FREE | 8x | 0.402$ |
| [M3 Brass Hot Melt Insert Knurled Nut][insert] - choice: _M3(OD4.2mm)_ , _Length 3mm 50pcs_ | 0.5$ | 2.05$ | 6x | 0.06$ |
| [3 pin 26AWG wire][wire] - choice: _30 core 5 meters_ | 1.49$ | 2.05$ | ~ 90cm | 0.268$ |
| [Dupont housing][housing] - choice: _1X3P_ | 1.08$ | 0.27$ | 10x | 0.108$ |
| [Dupont Terminal][female] - choice: Dupont Terminal | 0.95$ | 0.27$ | 36x | 0.342$ |
| **Sum:** | **9.78$** |  **5.13$** | -- | **2.902$** |

For all the products with shipping to Czech Republic i paid **14.91$**.

---

# Embedding Models

Before Embeding [models][models] onto the car create the needed [cables][cables] and insert all needed [insertion nuts][insert_nut].

When embedding the models onto the car, it is important to make sure that everything is secured properly and all cables are connected correctly. Start with the back lid. Connect the cables to the appropriate pins on the module.

Make sure all cables are tidy and out of the way of any moving parts. Once all models are embedded onto the car, test the IR sensors to ensure they are working properly. With all four sensors in place, the car should be able to detect obstacles in all directions.

---

## Back Lid

**Parts:**

- 1x Back Lid
- 2x insertion nuts
- 2x screws
- 1x 3pin dupont 5cm
- 1x 2pin dupont 8cm
- 1x 1pin dupont 8cm
- 1x [4 Channel Infrared Sensor Module][4_channel_IR]

<table>
  <tr>
    <td valign="top">Step 1: <a href="nut_insertion.md">Insert the 2 insertion nuts into the model</a></td>
    <td valign="top">step1</td>
  </tr>
  <tr>
    <td valign="top">Step 2: Screw the IR module in</td>
    <td valign="top">step2</td>
  </tr>
  <tr>
    <td valign="top">Step 3: Connect the <a href="crimping_cables.md">Cables</a> 
    <ul>
        <li>Connect the power and ground cables:
            <ul>
              <li>5V - VCC</li>
              <li>G - GND</li>
            </ul>
        </li>
        <li>Connect the sensors
          <ul>
            <li>Left sensor: P0 - OUT1</li>    
            <li>Left Front sensor: P7 - OUT2</li>
            <li>Right Front sensor: P12 - OUT3</li>
            <li>Right sensor: P13 - OUT4</li>
          <ul>
        </li>
    </ul>
    </td>
    <td valign="top">step3</td>
    <td valign="top">step3</td>
  </tr>
</table>

---

## Front Piece

**Parts:**

- 1x Front holder
- 4x LEGO Pin type 32002
- 2x insertion nuts
- 2x screws
- 2x 3pin dupont 20cm
- 2x IR sensors from [4 Channel Infrared Sensor Module][4_channel_IR]

<table>
  <tr>
    <td valign="top">Step 1: <a href="nut_insertion.md">Insert the 2 insertion nuts into the model</a></td>
    <td valign="top">step1</td>
  </tr>
  <tr>
    <td valign="top">Step 2: Insert 1 LEGO pin into each corner of the front LEGO plate</td>
    <td valign="top">step2</td>
  </tr>
  <tr>
    <td valign="top">Step 3: Place the model on the lego pins</td>
    <td valign="top">step3</td>
  </tr>
  <tr>
    <td valign="top">Step 4: Screw the IR sensors into the insertion nuts</td>
    <td valign="top">step4</td>
  </tr>
  <tr>
    <td valign="top">Step 5: Connect the <a href="crimping_cables.md">Cables</a></td>
    <td valign="top">step5</td>
    <td valign="top">step5</td>
  </tr>
  <tr>
    <td valign="top">Step 6: Place the ultrasonic sensor on top</td>
    <td valign="top">step6</td>
  </tr>
</table>

---

## Side Piece

**Parts:**

- 2x side holder - top piece
- 2x side holder - bottom piece
- 4x LEGO Pin type 32002
- 2x insertion nuts
- 2x screws
- 2x 3pin dupont 15cm
- 2x IR sensors from [4 Channel Infrared Sensor Module][4_channel_IR]

<table>
  <tr>
    <td valign="top">Step 1: <a href="nut_insertion.md">Insert the 2 insertion nuts into the models</a></td>
    <td valign="top">step1</td>
  </tr>
  <tr>
    <td valign="top">Step 2: Insert LEGO pins on the top of the LEGO plate</td>
    <td valign="top">step2</td>
  </tr>
  <tr>
    <td valign="top">Step 3: Place the bottom piece on the lego pieces</td>
    <td valign="top">step3</td>
  </tr>
  <tr>
    <td valign="top">Step 4: Place the top piece on the lego pins</td>
    <td valign="top">step4</td>
  </tr>
  <tr>
    <td valign="top">Step 5: Connect the <a href="crimping_cables.md">Cables</a></td>
    <td valign="top">step5</td>
    <td valign="top">step5</td>
    <td valign="top">step5</td>
  </tr>
</table>

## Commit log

2023-05-06 front part draft
    [front_binder.SLDPRT, front_bottom.SLDPRT, front_top.SLDPRT]
2023-05-06 front part fix plus back draft
    [back.SLDPRT, done_front.SLDPRT, front_binder.SLDPRT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]
2023-05-06 back fix + sides
    [back.SLDPRT, front.SLDPRT, side_bottom.SLDPRT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]
2023-05-06 fix + cable interconnection draft
2023-05-07 cables + box for charger
    [chrger_box.SLDPRT, chrger_lid.SLDPRT]
2023-05-07 stl files + crimping_cables.md
    [back.STL, charger_box.SLDPRT, charger_box.STL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]
2023-05-17 back lid fix
    [back.SLDPRT, back.STL]
2023-06-05 model addition
    [charger_box.SLDPRT, charger_box.STL, charger_lid.SLDPRT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]
2023-06-05 charger tutorial
